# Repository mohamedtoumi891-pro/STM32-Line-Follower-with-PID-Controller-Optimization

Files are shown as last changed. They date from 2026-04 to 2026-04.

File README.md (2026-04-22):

# STM32-Line-Follower-with-PID-Controller-Optimization — BACHAWANGUI


[]()
[]()
[]()

> **BACHAWANGUI** is a fully autonomous line-following robot designed and built from scratch for the **ROBOCUP ENSI 7.0** competition. The project encompasses mechanical design (SolidWorks), custom PCB design (KiCad), embedded firmware (PID control), and 3D component modeling.

---

## 📸 PCB Design & Wiring Schematic

<p align="center">
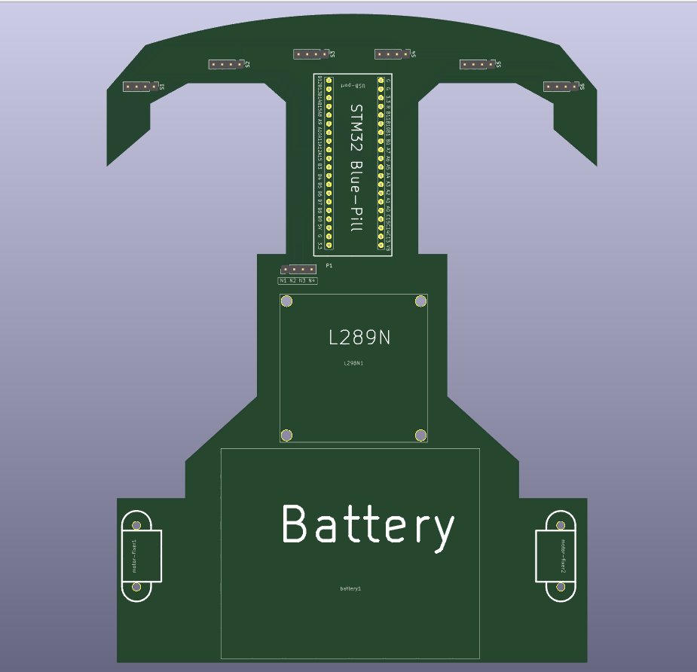
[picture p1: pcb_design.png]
BACHAWANGUI Custom PCB Design — KiCad 3D View
  
  &nbsp;&nbsp;
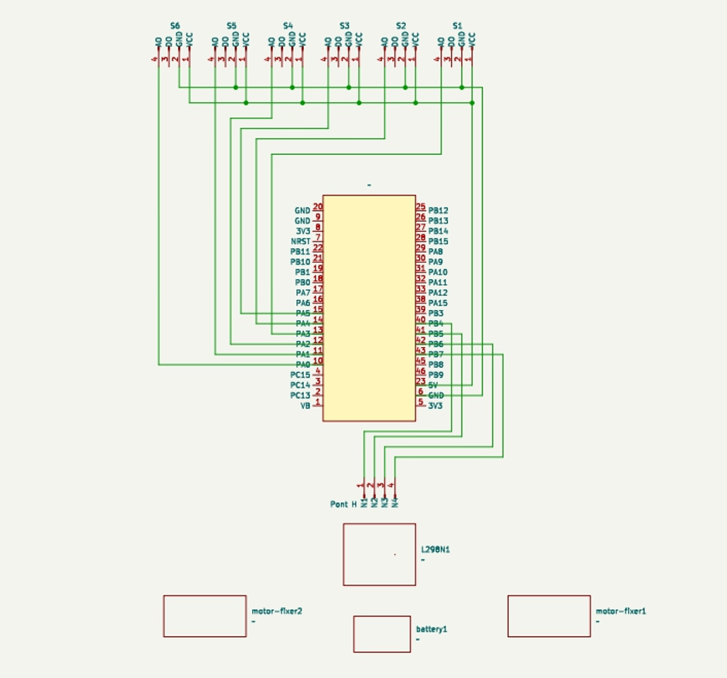
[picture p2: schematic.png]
BACHAWANGUI Wiring Schematic
  
</p>

<p align="center">
  <em>Left: Custom PCB layout (KiCad) — STM32 Blue Pill, L298N, Battery, N20 Motors &amp; IR Sensors integrated</em><br/>
  <em>Right: Full wiring schematic — sensor array, MCU, motor driver &amp; power connections</em>
</p>

---

## 📌 Abstract

In this project, a modified PID controller and open-loop control mechanisms were implemented to improve the stability and robustness of a differential wheeled robot. A test platform was constructed using low-cost, off-the-shelf components including a microcontroller, IR reflectance sensors, and a motor driver. This document describes the heuristic approach used for system identification and controller optimization. The PID controller is analyzed in detail, with the effect of each term explained in the context of line-following stability. Challenges encountered during hardware and software development are also discussed.

---

## 🏗️ Project Architecture

```
BACHAWANGUI/
│
├── ⚙️  Mécanique     → Chassis design (SolidWorks), MDF cutting, assembly
├── ⚡  Électrique     → Wiring, sensor integration, motor connections
├── 💻  Informatique  → PID firmware (Arduino C++), strategy selection
└── 🖥️  PCB Design    → Custom PCB (KiCad), 3D footprints from scratch
```

---

## 🧩 Components

| Component | Description | Quantity |
|---|---|---|
| **STM32 Blue Pill** (STM32F103C8) | Main MCU — later replaced by Arduino Mega | 1 |
| **Arduino Mega** | Final competition MCU | 1 |
| **N20 DC Motors** | Micro gear motors (6V) | 2 |
| **IR Sensors** | Infrared line detection sensors | 6 |
| **L298N Motor Driver** | Dual H-bridge motor driver module | 1 |
| **Carte de Puissance** | Custom power management board | 1 |
| **Battery Pack (3× AA)** | 4.5V power supply | 1 |
| **Scroll wheel** | Front passive caster wheel | 1 |
| **MDF Chassis** | Custom-cut wooden frame | 1 |

---

## 🖥️ Software Stack

| Layer | Tool / Framework |
|---|---|
| Mechanical CAD | SolidWorks |
| PCB Design | KiCad |
| 3D Component Modeling | SolidWorks / KiCad 3D |
| Embedded Firmware | Arduino C++ / STM32 HAL (C) |
| Schematic Design | KiCad Schematic Editor |

---

## 🔌 Wiring & Schematic

The wiring connects 6 independent IR sensors to the microcontroller's digital inputs (PA0–PA5), which runs a PID control loop and outputs PWM signals to the L298N motor driver (via PB0, PB1, PB6, PB7), which in turn drives the two N20 motors.

```
[6× IR Sensors] ──(OUT)──► [STM32 / Arduino Mega]
                                     │
                              [PID Algorithm]
                                     │
                            [L298N Motor Driver]
                               /            \
                       [N20 Motor L]    [N20 Motor R]
                       
[Battery Pack] ──(+4.5V)──► [L298N 12V] ──(5V reg.)──► [IR Sensors VCC]
[Battery Pack] ──(GND)   ──► [Common Ground Rail]
```

<p align="center">
  Full Wiring Schematic
</p>

### Pin Mapping

| STM32 / Arduino Pin | Connected To |
|---|---|
| PA0 | IR Sensor 1 — OUT |
| PA1 | IR Sensor 2 — OUT |
| PA2 | IR Sensor 3 — OUT |
| PA3 | IR Sensor 4 — OUT |
| PA4 | IR Sensor 5 — OUT |
| PA5 | IR Sensor 6 — OUT |
| PB0 | L298N — IN1 |
| PB1 | L298N — IN2 |
| PB6 | L298N — IN3 |
| PB7 | L298N — IN4 |
| PA6 | L298N — ENA (PWM) |
| PA7 | L298N — ENB (PWM) |
| 3.3V / 5V | IR Sensors — VCC |
| GND | Common ground |

---

## ⚙️ Mechanical Design

The chassis was designed in **SolidWorks** then cut from **MDF wood**. A rear perpendicular support bracket was attached to hold the motor assembly. Key design constraints followed the **ROBOCUP ENSI 7.0** specifications.

<p align="center">
  <!-- SolidWorks chassis design — see Main_System_Assembly in the dossier -->
</p>

---

## 🖨️ PCB Design

A **custom PCB** was designed in **KiCad** to integrate all components onto a single board, eliminating loose wiring and improving reliability. Key contributions include:

- ✅ **STM32 Blue Pill** — full schematic symbol, PCB footprint, and 3D model created from scratch
- ✅ **N20 Motors** — custom mounting footprint and 3D model
- ✅ **IR Sensors** — custom connector footprint (6× individual sensors)
- ✅ **Power board (Carte de Puissance)** — custom slot and footprint
- ✅ **Battery holders (3× AA)** — custom 3D model and footprint
- ✅ **Scroll wheel** — custom 3D model for spatial validation

> 💡 All custom KiCad library assets are located in `/hardware/lib/`

---

## 🧠 PID Controller

The robot uses a **PID (Proportional-Integral-Derivative)** controller to follow the line with minimal oscillation:

```
error       = sensor_weighted_position − setpoint
correction  = Kp×error + Ki×∫error dt + Kd×d(error)/dt

motor_left  = base_speed + correction
motor_right = base_speed − correction
```

Parameters Kp, Ki, Kd were tuned heuristically during testing sessions. The sensor array of **6 IR sensors** provides a weighted position estimate of the line relative to the robot center.

---

## 📁 Repository Structure

```
BACHAWANGUI/
│
├── firmware/
│   ├── stm32/              # Original STM32 HAL firmware (C)
│   └── arduino/            # Final competition firmware (Arduino C++)
│       └── pid_linefollower.ino
│
├── hardware/
│   ├── schematics/         # KiCad schematic files (.kicad_sch)
│   ├── pcb/                # PCB layout files (.kicad_pcb)
│   ├── lib/                # Custom footprints, symbols & 3D models
│   │   ├── stm32_bluepill/
│   │   ├── n20_motor/
│   │   ├── ir_sensor/
│   │   ├── power_board/
│   │   └── battery_holder/
│   └── gerbers/            # Manufacturing-ready Gerber files
│
├── mechanical/
│   └── solidworks/         # SolidWorks chassis & component files (.SLDPRT)
│
├── docs/
│   ├── robot_photo.jpg        # Robot photo (ROBOCUP competition)
│   ├── DOSSIER-TECHNIQUE.pdf  # Full technical dossier
│   └── Main_System_Assembly/  # SolidWorks 3D assembly files
│
├── PCB_part/                  # KiCad PCB project files
│   ├── *.kicad_pcb
│   ├── *.kicad_sch
│   └── lib/                   # Custom footprints & 3D models
│
├── pcb_design.png             # PCB 3D render (KiCad)
└── schematic.svg              # Wiring schematic diagram
│
└── README.md
```

---

## 🚀 Getting Started

### Requirements

- [Arduino IDE](https://www.arduino.cc/en/software) — for Arduino Mega firmware
- [STM32CubeIDE](https://www.st.com/en/development-tools/stm32cubeide.html) — for STM32 firmware
- [KiCad 7+](https://www.kicad.org/) — for PCB files
- [SolidWorks 2022+](https://www.solidworks.com/) — for mechanical files

### Build & Upload (Arduino)

```bash
# 1. Open firmware/arduino/pid_linefollower.ino in Arduino IDE
# 2. Select: Tools → Board → Arduino Mega 2560
# 3. Select the correct COM port
# 4. Click Upload
```

---

## 🏁 Competition

The **BACHAWANGUI** robot was entered into the **ROBOCUP ENSI 7.0** competition, organized under the **AEROBOTIX** club (robotics & aeronautics pole of INSAT). The robot competed on both straight and curved track segments.

> Mid-development, the STM32 Blue Pill was replaced with an **Arduino Mega** to resolve firmware timing issues under competition deadline pressure. The team adapted rapidly and competed successfully — a real lesson in engineering resilience and adaptability.

---

## 👥 Team & Club

**Club:** [AEROBOTIX](https://www.instagram.com/aerobotix.insat/) — Pôle Robotique & Aéronautique de l'INSAT  
> AEROBOTIX is Tunisia's leading robotics and aeronautics club with 150+ members, 100+ national competition entries, 17 international participations, and 35+ medals.

| Role | Contribution |
|---|---|
| PCB Design & Hardware | Custom PCB, KiCad footprints, 3D models |
| Mechanical Design | SolidWorks chassis, MDF fabrication |
| Firmware | PID algorithm, Arduino/STM32 |
| Electronics | Wiring, sensor integration, power management |

---

## 📄 License

This project is licensed under the [MIT License](LICENSE).

---

> *"The best engineering happens when creativity meets constraints."*

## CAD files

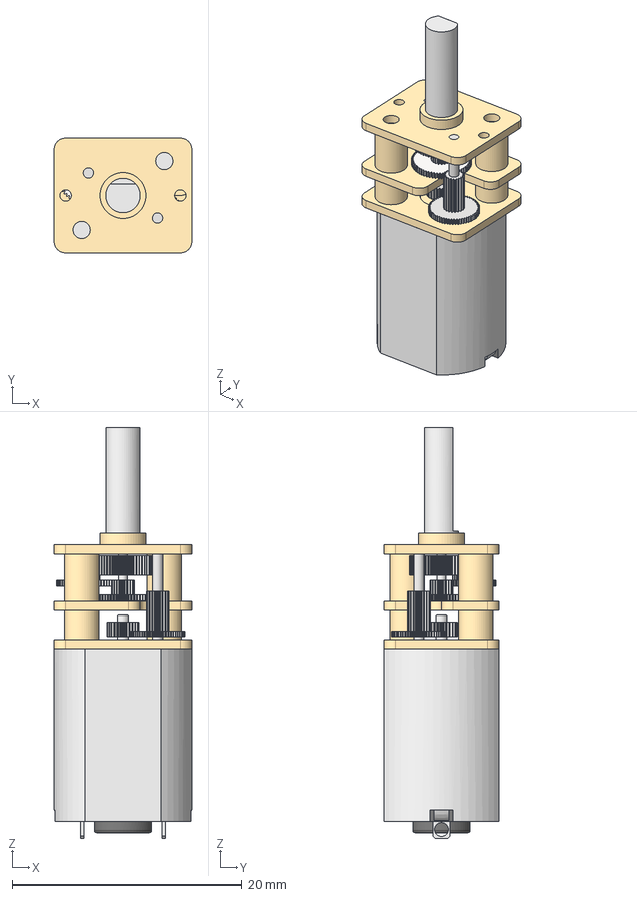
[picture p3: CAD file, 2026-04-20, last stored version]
suiveur/Main_System_Assembly/N20 DC Gear Motor.step
12.0 x 10.0 x 35.8 mm
Gear Box
Shaft
Motor

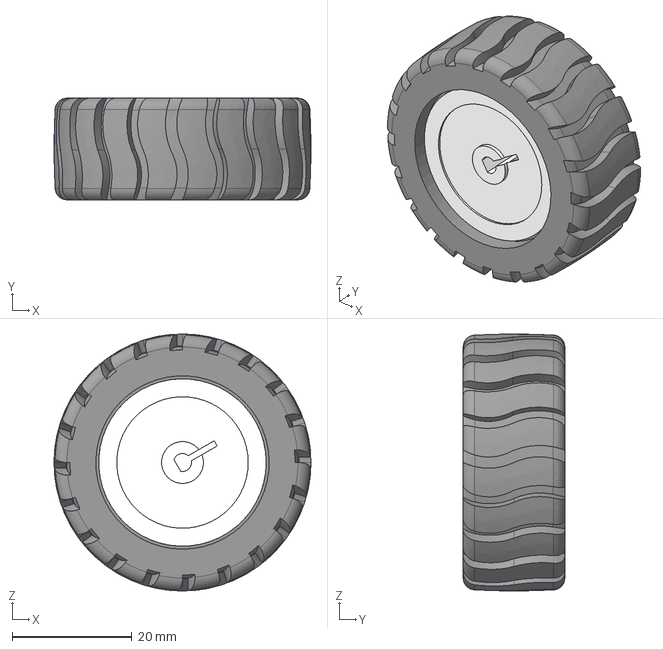
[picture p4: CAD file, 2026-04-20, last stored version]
suiveur/Main_System_Assembly/N20 wheel.step
43.0 x 17.0 x 43.0 mm

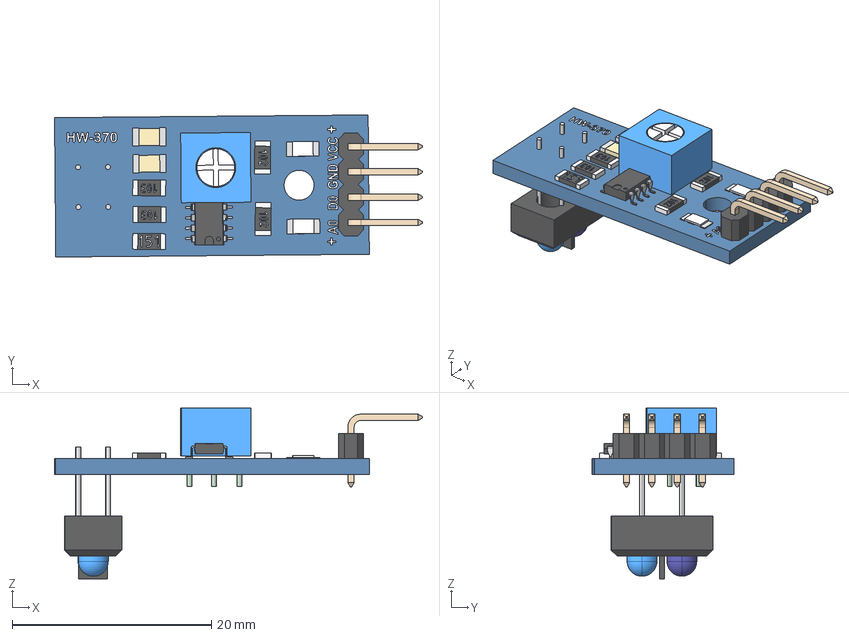
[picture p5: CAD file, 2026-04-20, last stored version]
suiveur/Main_System_Assembly/TCRT5000.stp
37.0 x 14.3 x 17.1 mm
TCRT5000
leds Geometry
pin
IC_smd_8
smd_10k Geometry x 2
cover x 2
smd_150 Geometry
cover2
Surf Geometry x 2
cover3 x 2
LED_SMD x 2
smd_1k Geometry x 2
cover4 x 2
pot Geometry
pin2
leds2 Geometry
pins
Board Geometry
TXT
4PinsOut Geometry
pin3

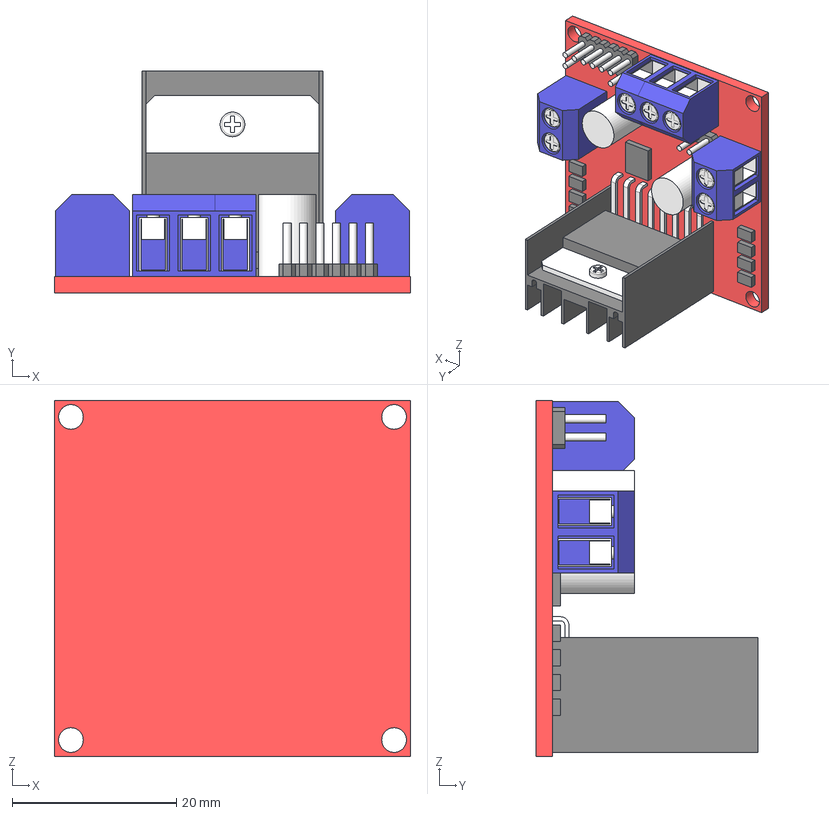
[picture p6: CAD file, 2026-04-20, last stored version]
suiveur/Main_System_Assembly/L298N Motor Driver.step
43.3 x 27.0 x 43.3 mm
Pcb
Pengunci x 2
Pengunci 2

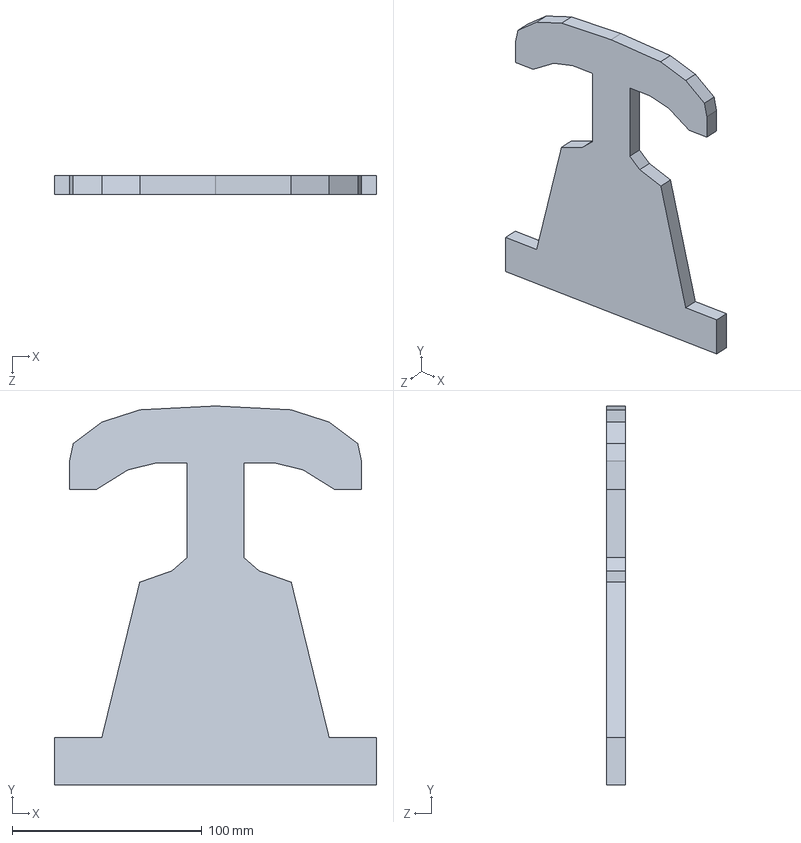
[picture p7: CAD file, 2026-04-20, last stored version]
suiveur/Main_System_Assembly/base.SLDPRT
170.0 x 200.0 x 10.0 mm

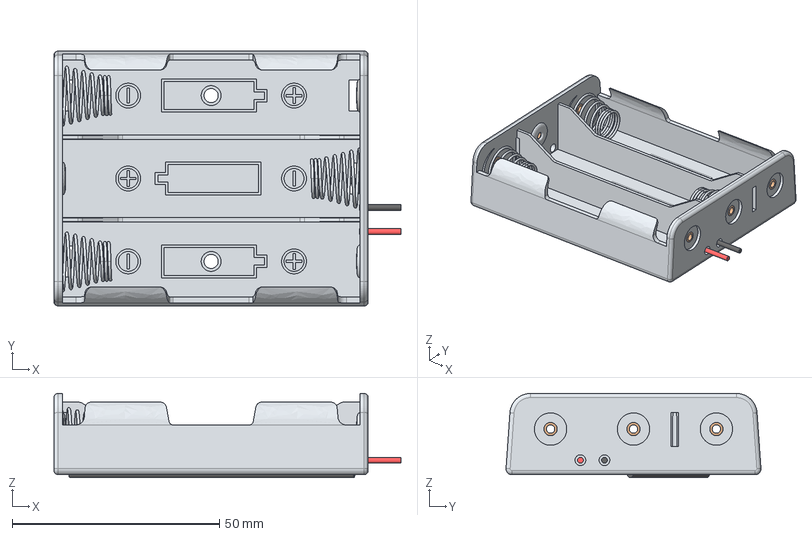
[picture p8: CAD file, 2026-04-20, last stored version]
suiveur/Main_System_Assembly/batteryCase18650x3.step
83.7 x 61.5 x 20.3 mm
Corps
FilNoirUnder001
Positif1
Spring1
Spring3
rivet x 6
Positif2
Positif3
FilRouge
FilNoir
FilNoirUnder

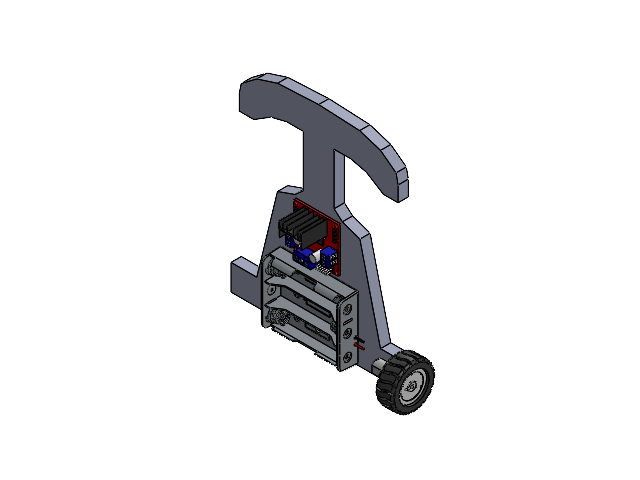
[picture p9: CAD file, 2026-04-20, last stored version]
suiveur/Main_System_Assembly/Assemblage26.SLDASM
base
n20 wheel

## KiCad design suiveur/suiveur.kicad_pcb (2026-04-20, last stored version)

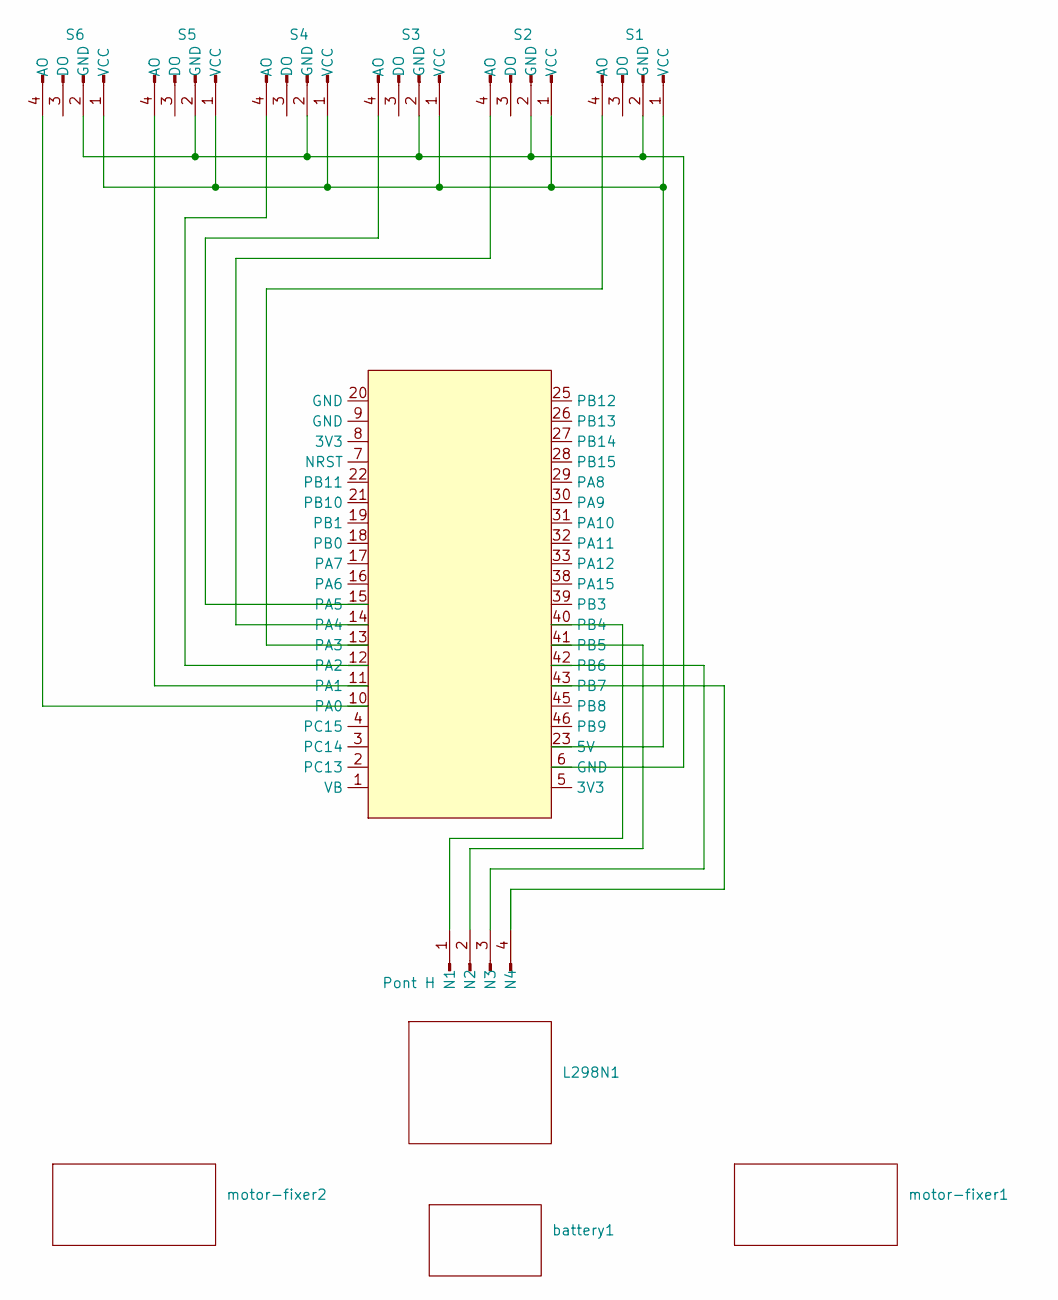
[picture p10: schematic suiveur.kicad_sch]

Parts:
L298N1: L289N
P1: Pont H; PinHeader_1x04_P2.54mm_Vertical
S1, S2, S3, S4, S5, S6: TCRT5000; PinHeader_1x04_P2.54mm_Vertical
STM32-BluePill1: stm32 blue pill
battery1: battery
motor-fixer1, motor-fixer2: motor fixer

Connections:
unnamed: P1.1 (N1), STM32-BluePill1.40 (PB4)
unnamed: P1.2 (N2), STM32-BluePill1.41 (PB5)
unnamed: P1.3 (N3), STM32-BluePill1.42 (PB6)
unnamed: P1.4 (N4), STM32-BluePill1.43 (PB7)
unnamed: S1.4 (AO), STM32-BluePill1.13 (PA3)
unnamed: S1.2 (GND), S2.2 (GND), S3.2 (GND), S4.2 (GND), S5.2 (GND), S6.2 (GND), STM32-BluePill1.6 (GND)
unnamed: S1.1 (VCC), S2.1 (VCC), S3.1 (VCC), S4.1 (VCC), S5.1 (VCC), S6.1 (VCC), STM32-BluePill1.23 (5V)
unnamed: S2.4 (AO), STM32-BluePill1.14 (PA4)
unnamed: S3.4 (AO), STM32-BluePill1.15 (PA5)
unnamed: S4.4 (AO), STM32-BluePill1.12 (PA2)
unnamed: S5.4 (AO), STM32-BluePill1.11 (PA1)
unnamed: S6.4 (AO), STM32-BluePill1.10 (PA0)

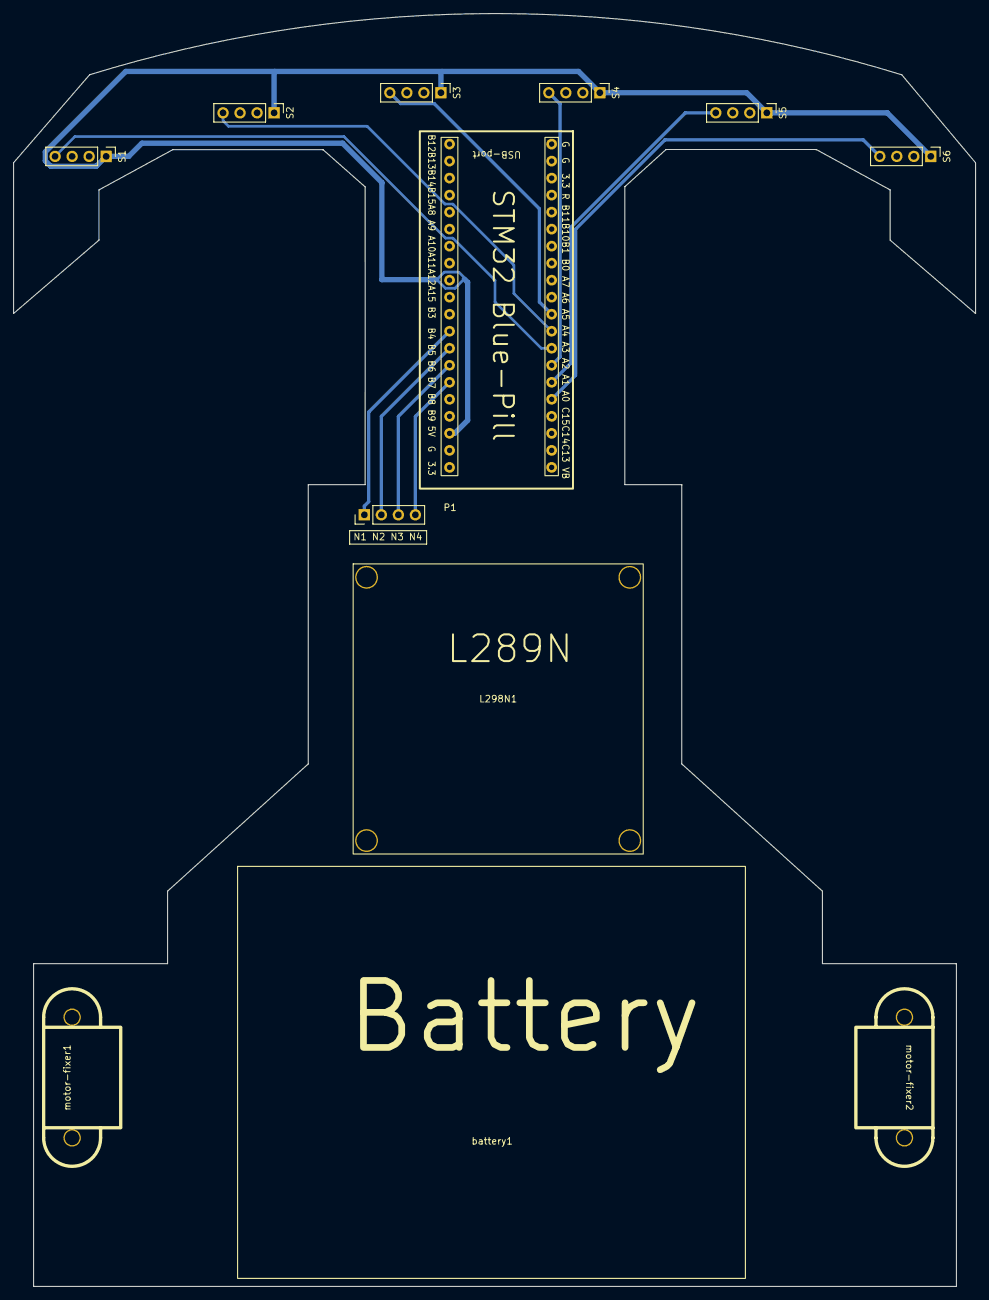
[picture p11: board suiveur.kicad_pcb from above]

Board: 2 copper layers, 143.6 x 190.0 mm, 12 parts (0 on the bottom side), 12 nets.

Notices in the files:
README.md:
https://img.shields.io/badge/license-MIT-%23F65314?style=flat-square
